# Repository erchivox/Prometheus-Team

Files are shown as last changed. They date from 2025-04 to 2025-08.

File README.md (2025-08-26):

# Prometheus Team

Somos un equipo venezolano que representa con orgullo a la **Universidad Politécnica Territorial José Félix Ribas (UPTJFR)**. Nuestro compromiso es la innovación y el aprendizaje continuo en el campo de la robótica autónoma.

---

##  Índice

* [Contenido del Repositorio](#contenido-del-repositorio)
* [Introducción al Proyecto](#introducción-al-proyecto)
* [Fotos de Equipo](#fotos-de-equipo)
* [Fotos del Vehículo](#fotos-del-vehiculo)
* [Diseño de Hardware](#diseño-de-hardware)
   * [Componentes de Detección](#componentes-de-detección)
   * [Componentes de Procesamiento de Información](#componentes-de-procesamiento-de-información)
   * [Componentes de Alimentación](#componentes-de-alimentación)
* [Desarrollo de la Aplicación para la Detección de Objetos](#Desarrollo-de-la-Aplicación-para-la-Detección-de-Objetos)
* [Cálculo de Torque y Velocidad](#cálculo-de-torque-y-velocidad)
* [Sistema de Alimentación](#sistema-de-alimentación)
   * [Cálculo del Consumo Energético Total](#cálculo-del-consumo-energético-total)
   * [Autonomía Estimada](#autonomía-estimada)
* [Sistema de Detección de Objetos](#sistema-de-detección-de-objetos)
* [Paso a Paso de la Construcción](#paso-a-paso-de-la-construcción)
   * [Etapa de Diseño y Ensamblaje del Vehículo](#etapa-de-diseño-y-ensamblaje-del-vehículo)
   * [Montaje del Vehículo](#montaje-del-vehículo)
   * [Diseño de Base 3D](#diseño-de-base-3d)
   * [Cambio de Base](#cambio-de-base)
   * [Problemas Encontrados](#problemas-encontrados)
* [Pruebas Realizadas](#pruebas-realizadas)
   * [Prueba del Sensor de Color](#prueba-del-sensor-de-color)
   * [Fabricación de Pista a Escala](#fabricacion-de-pista-a-escala)
   * [Desarrollo de la Lógica de Vueltas a la Pista](#desarrollo-de-la-logica-de-vueltas-a-la-pista)
   * [Desarrollo de la Lógica de Evasión de Objetos](#desarrollo-de-la-logica-de-evasion-de-objetos)
   * [Desarrollo de Códigos Combinados](#desarrollo-de-códigos-combinados)
   * [Video Resumen de las Pruebas](#video-resumen-de-las-pruebas-de-vuelta-a-la-pista-y-esquive-de-objetos)
   * [Prueba de Vueltas a la Pista](#prueba-de-vueltas-a-la-pista)
   * [Prueba de Evasión de Obstáculos](#prueba-de-evacion-de-obstaculos)
---

##  Contenido del Repositorio

Este repositorio contiene los siguientes directorios para organizar nuestro proyecto:

* `t-photos`: Incluye 2 fotos del equipo (una oficial y una divertida con todos los miembros).
* `v-photos`: Contiene 6 fotos del vehículo (desde todos los ángulos, superior e inferior).
* `video`: Archivo `video.md` con el enlace a un video de demostración de conducción.
* `schemes`: Diagramas esquemáticos (JPEG, PNG o PDF) de los componentes electromecánicos, ilustrando la conexión de elementos electrónicos y motores.
* `src`: Código del software de control para todos los componentes programados para la competición.
* `models`: Archivos para modelos usados por impresoras 3D, cortadoras láser y máquinas CNC para producir elementos del vehículo.
* `other`: Archivos adicionales para entender cómo preparar el vehículo para la competición (documentación de conexión SBC/SBM, carga de archivos, especificaciones de hardware, etc.).

---

##  Introducción al Proyecto

Para esta competición, hemos desarrollado un diseño de vehículo **cómodo, fácil de modificar y sencillo**, donde todos los elementos interactúan a la perfección. Nos enorgullece presentar nuestro primer prototipo de vehículo autónomo con reconocimiento de objetos y colores.

El diseño y la construcción de nuestro vehículo son íntegramente propios. Su **estructura de dos niveles** permite que todos los componentes encajen armoniosamente. Incorpora **vigas de soporte extraíbles** para facilitar el desmontaje, un **sistema de transmisión** tipo LEGO que transfiere la potencia del motor a las ruedas traseras, y un **sistema de dirección** también con piezas LEGO, controlado por un servomotor para mayor precisión en los giros.

Este proyecto ha sido el resultado del esfuerzo y la dedicación de todo nuestro equipo. Cada cable, cada sensor, y cada línea de código es un testimonio de nuestro **esfuerzo técnico y financiero**. No solo construimos un vehículo; demostramos que con pasión y ganas de aprender, se pueden superar los límites.

---
##  Fotos de equipo
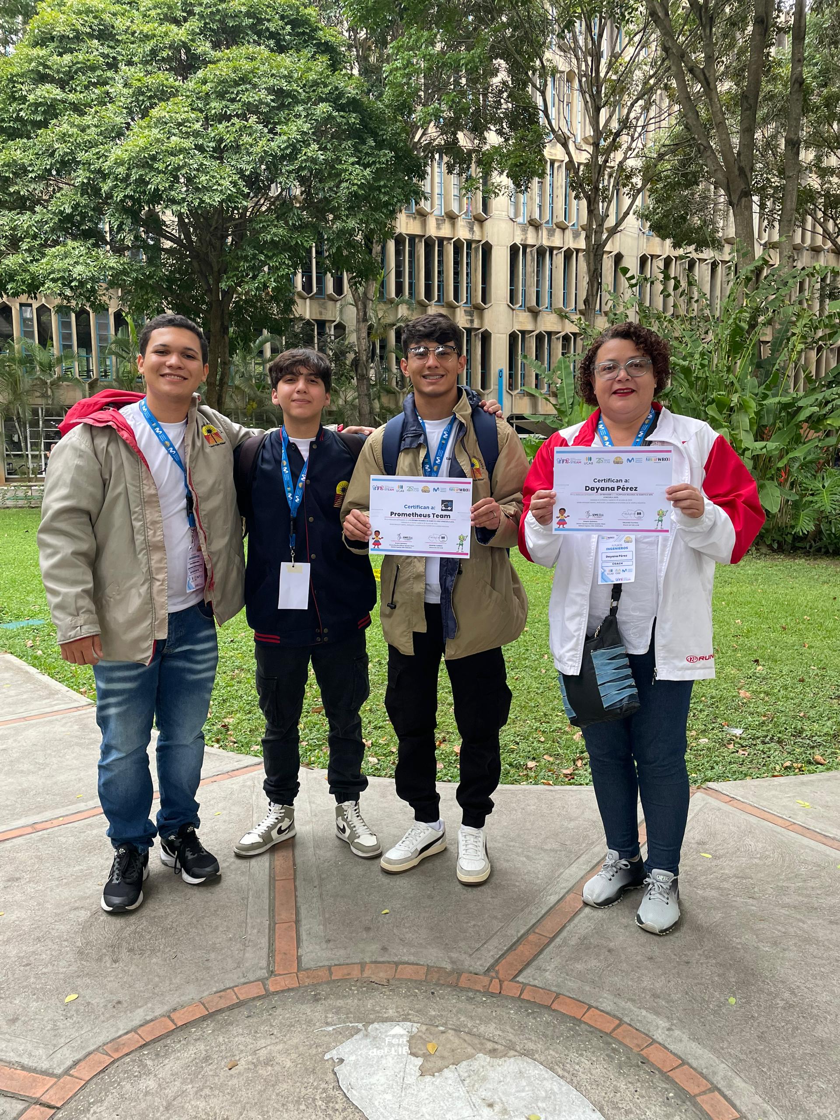
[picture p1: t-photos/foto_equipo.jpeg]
Foto Oficial
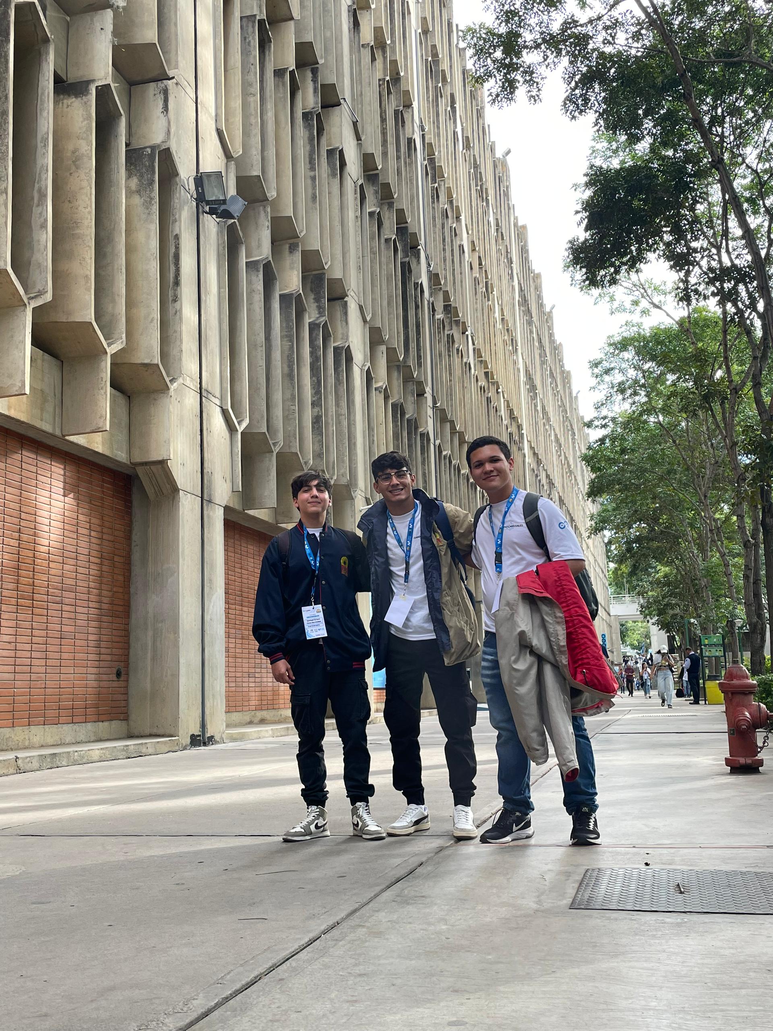
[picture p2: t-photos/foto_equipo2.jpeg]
Foto Equipo
|   |  | 
| :----: | :--- |

---
##  Fotos del vehiculo 
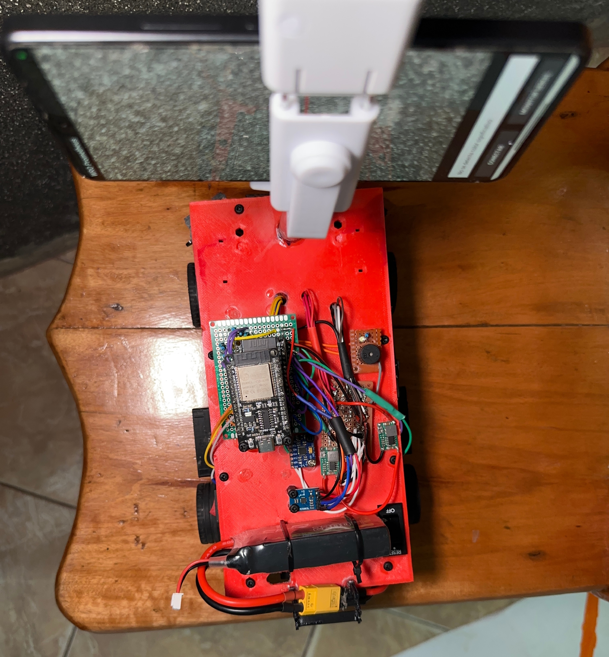
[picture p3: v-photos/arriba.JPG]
Arriba del vehiculo
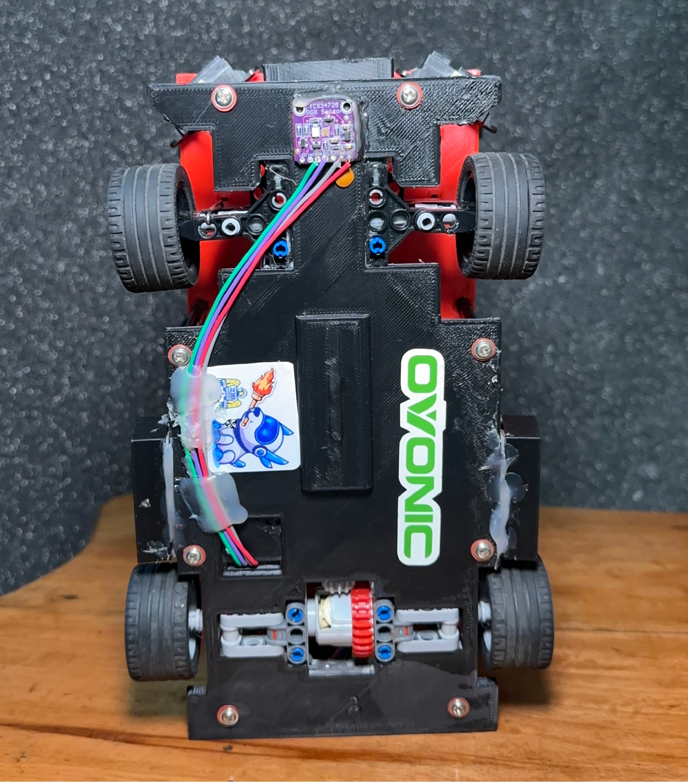
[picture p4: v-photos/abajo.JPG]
Debajo de vehiculo
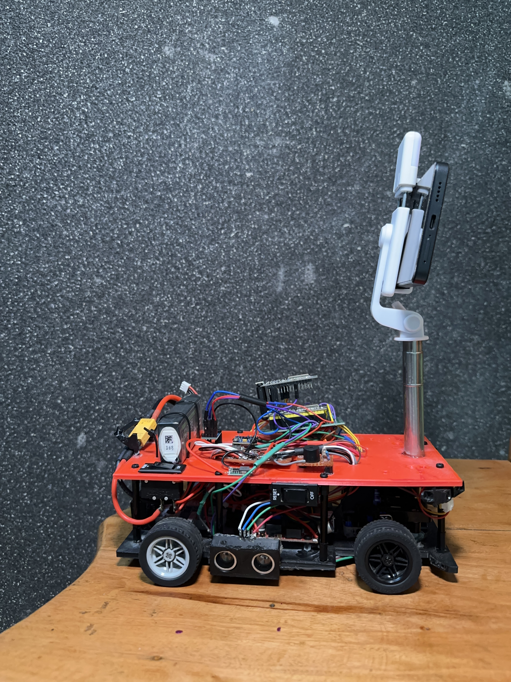
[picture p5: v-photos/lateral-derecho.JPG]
Lateral derecho
|   |    |   |
| :----: | :--- | :--- |
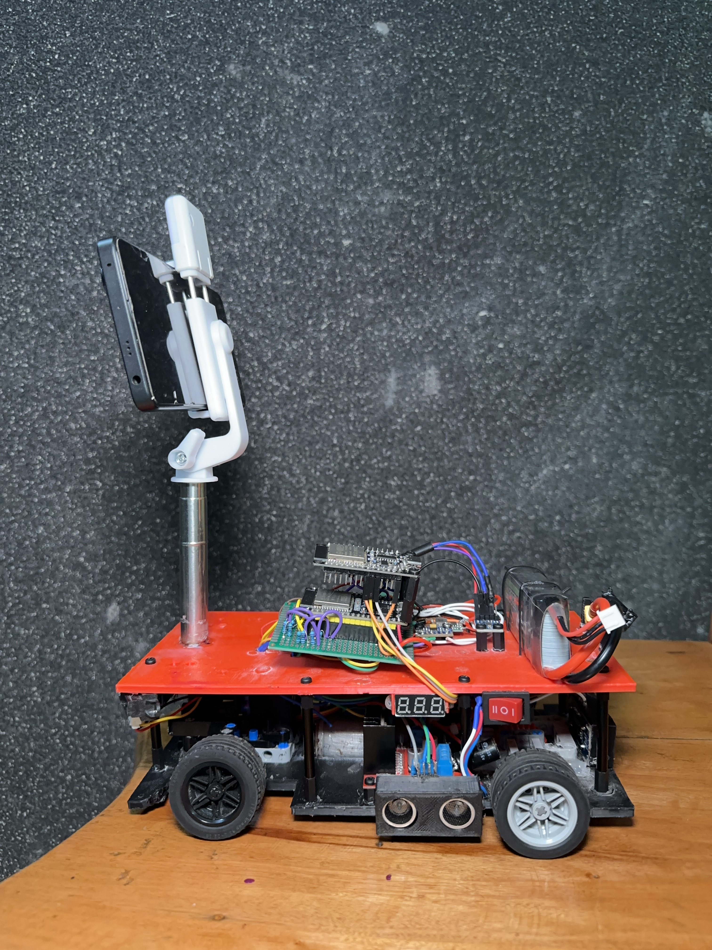
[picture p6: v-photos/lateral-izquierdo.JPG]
lateral izquierdo
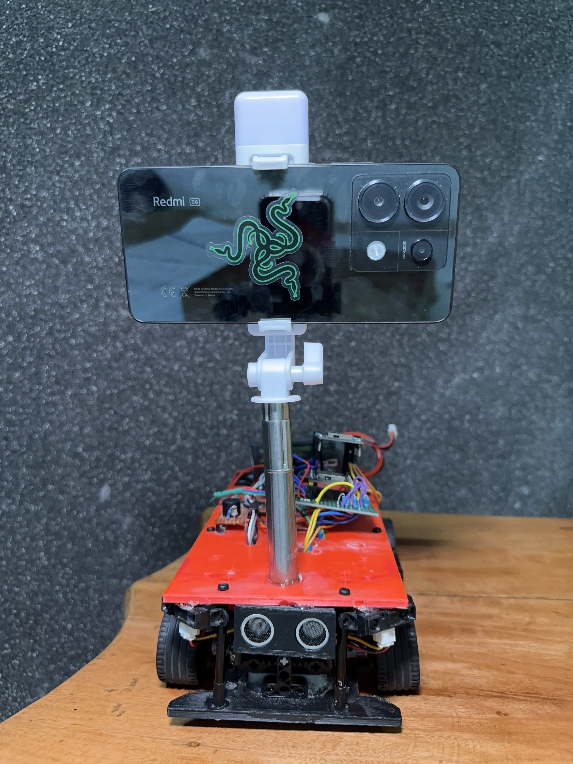
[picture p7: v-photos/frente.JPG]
frente
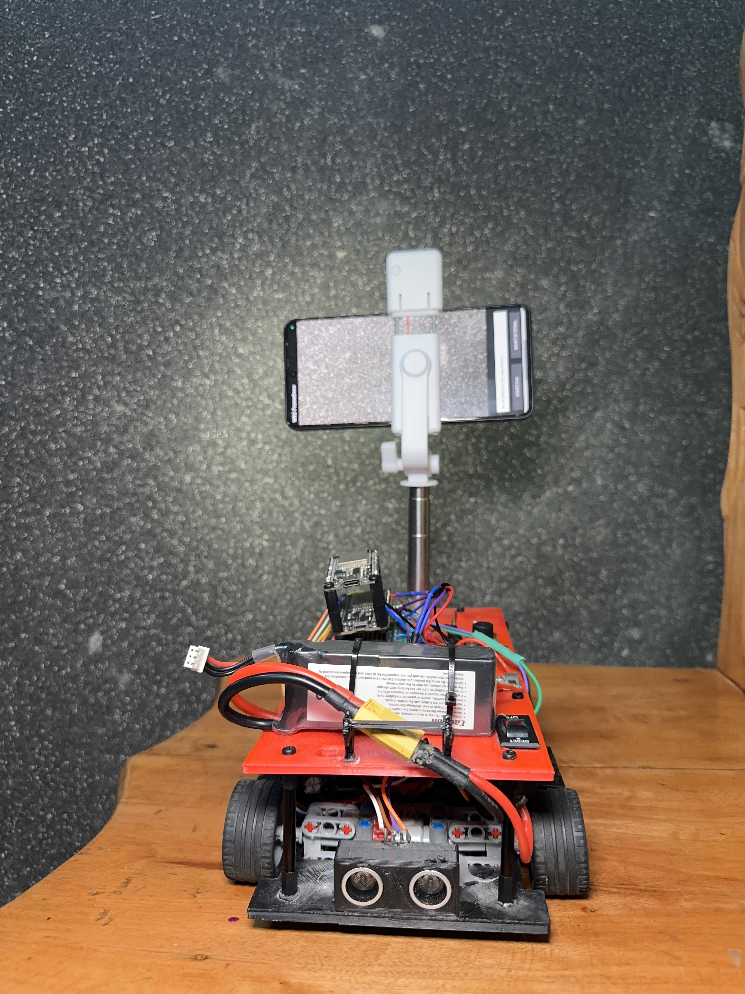
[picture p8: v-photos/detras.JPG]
detras
|   |    |   |

---

##  Diseño de Hardware

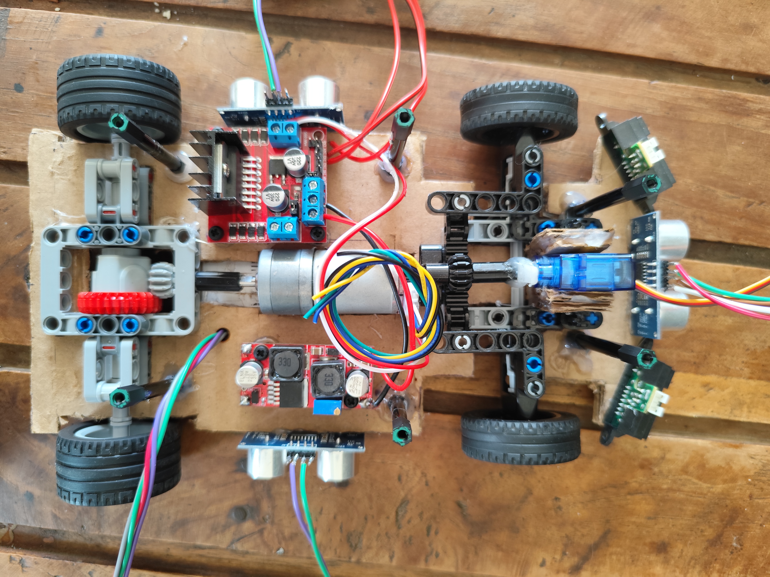
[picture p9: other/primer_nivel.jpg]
Control Principal


| Imagen | Nombre de Componente | Descripción |
| :----: | :--- | :--- |
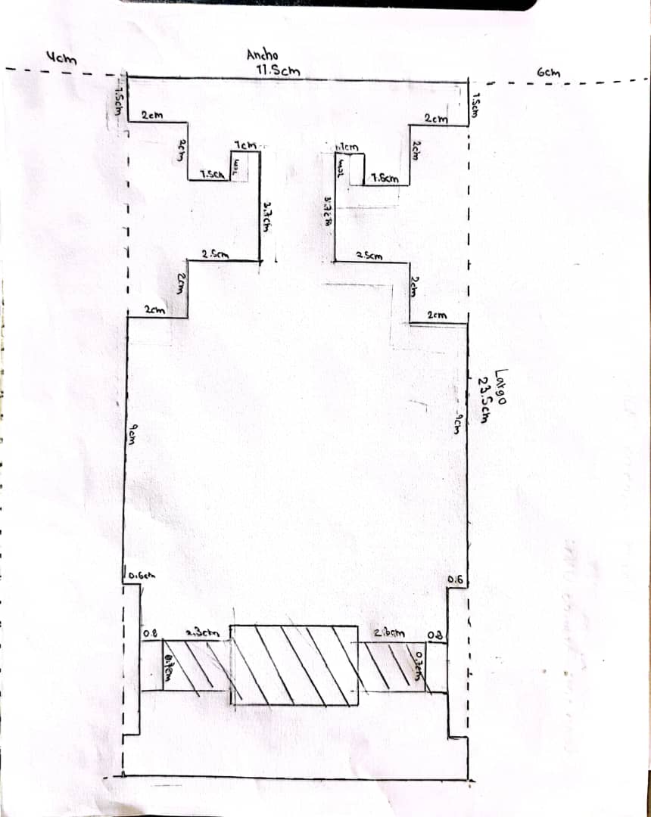
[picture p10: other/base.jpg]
Base del Primer Piso
|  | **Base del Vehículo** | Con medidas de 11.5 cm x 2.5 cm, imita un coche de Fórmula 1, optimizando la distribución de espacio y la movilidad. La parte frontal permite alojar tres sensores (1 ultrasónico central y 2 infrarrojos diagonales). Aunque el cartón inicial presentó debilidades en la dirección, el uso de acrílico o un material más rígido es la solución ideal. |
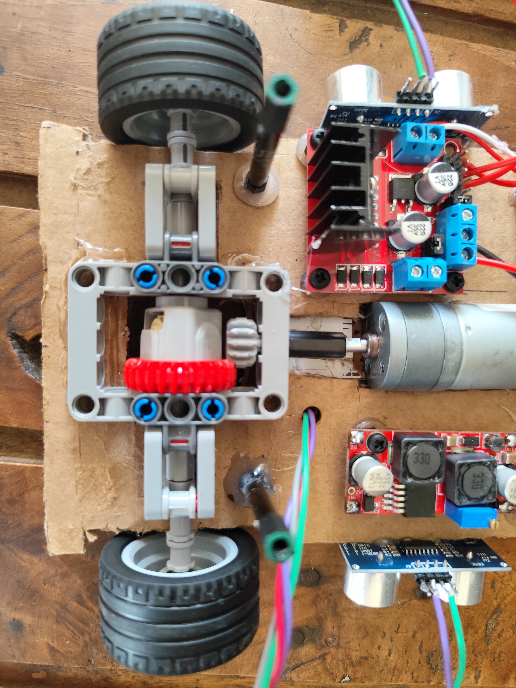
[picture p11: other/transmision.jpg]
Transmisión
|  | **Sistema de Transmisión de Legos** | Distribuye la potencia del motor entre ambas ruedas traseras, permitiendo el giro continuo del motor incluso si una rueda se bloquea y evitando daños. Elegido por su facilidad de uso y tamaño adecuado, permite también la reversa. |
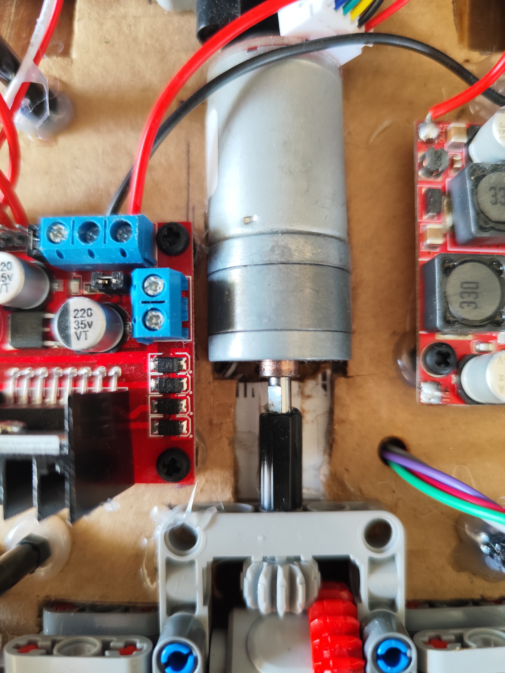
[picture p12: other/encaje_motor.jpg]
Motor
|  | **25GA370 Motor DC con Encoder** | Motor común en estos vehículos por su potencia y velocidad. El codificador integrado mide velocidad y dirección (aún no utilizado). **Especificaciones**: Potencia nominal: 4 W, Tensión nominal: 6V, Velocidad nominal: 220 RPM, Peso: 400g, Caja reductora: 21.3:1, Torque nominal: 0.35 kg·cm. |
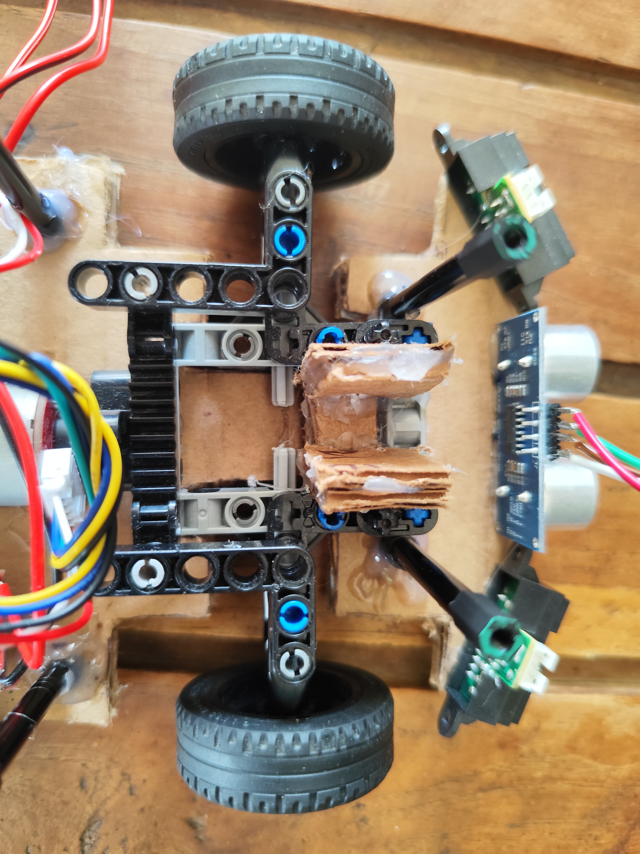
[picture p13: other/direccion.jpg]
Dirección
|  | **Sistema de Dirección** | Construido con piezas LEGO, su tamaño es ideal y permite adaptar un servomotor de 180 grados para controlar el movimiento. El servomotor se centra a 90 grados, gira a la izquierda a 180 grados y a la derecha a 0 grados. |
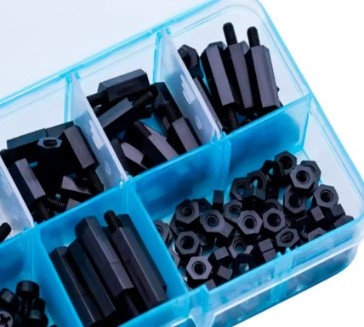
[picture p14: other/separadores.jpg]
Separadores
|  | **Separadores de Acrílico** | Facilitan un montaje cómodo y modular. Girar los pilares permite desatornillar y desmontar el vehículo rápidamente. |

### Componentes de Detección

| Imagen | Nombre de Componente | Descripción |
| :----: | :--- | :--- |
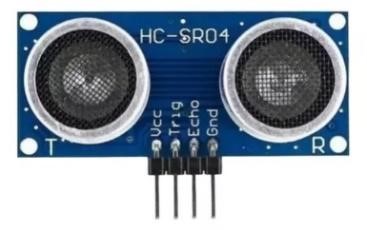
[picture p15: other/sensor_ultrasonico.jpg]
Sensor Ultrasónico
|  | **Sensor Ultrasónico HC-SR04** | Mide la distancia a obstáculos mediante ondas ultrasónicas. Lo utilizamos en la parte frontral, lateral izquierda, lateral derecha y en la parte trasera del vehiculo para detectar proximidad. |
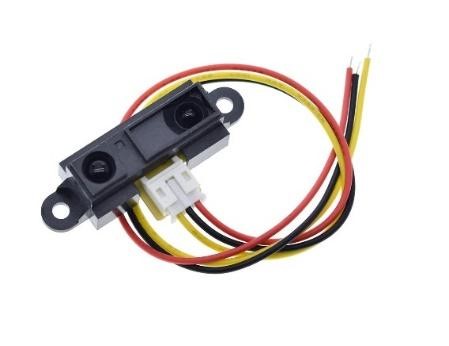
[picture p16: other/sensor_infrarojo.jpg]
Sensor Infrarrojo
|  | **Sharp GP2Y0A21YK0F Sensor Infrarrojo** | Garantiza una detección de objetos rápida y precisa. Se ubican en las diagonales delanteras del vehículo. |
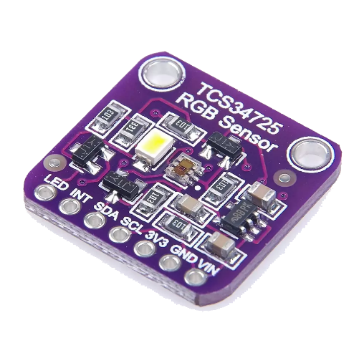
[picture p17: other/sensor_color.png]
Sensor Color
|  | **TCS34725 Sensor de Colores** | Permite una detección precisa del color a corta distancia, ubicado en la parte inferior para identificar los colores de las franjas de la pista. Alta sensibilidad y amplio rango dinámico (3.800.000:1), funcionando incluso tras cristales oscuros. |
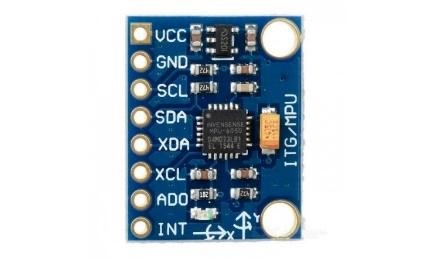
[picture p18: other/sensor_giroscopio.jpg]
Giroscopio
|  | **MPU6050 Sensor Giroscopio y Acelerómetro** | Unidad de medición inercial (IMU) de 6 grados de libertad (DoF) que combina un acelerómetro y un giroscopio de 3 ejes. Ampliamente utilizado en navegación, radiogoniometría y estabilización. |
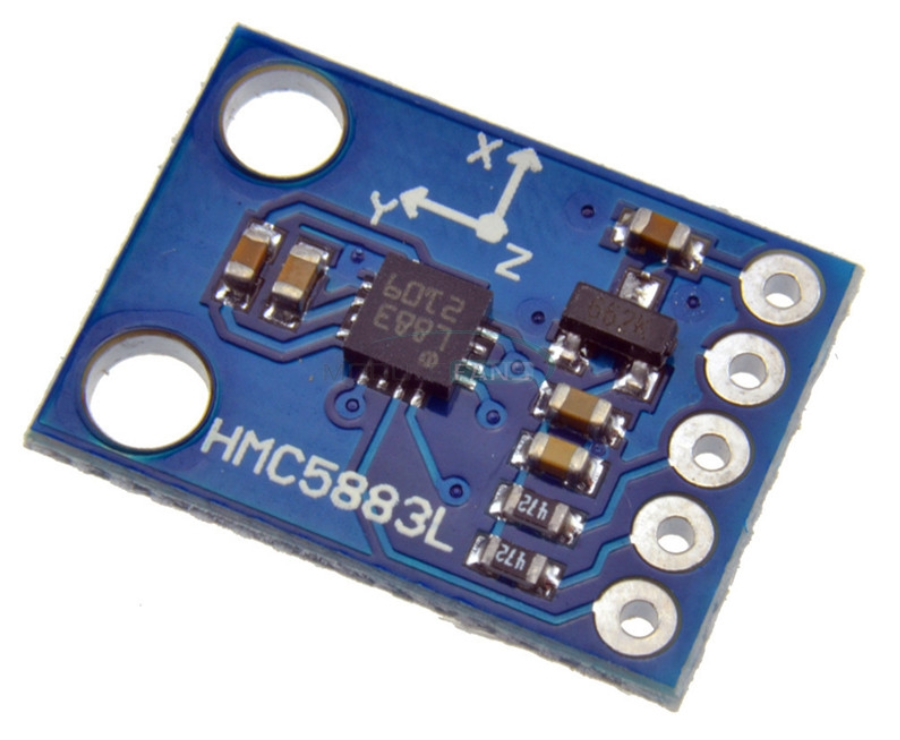
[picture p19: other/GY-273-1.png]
Magnetometro
|  | **Magnetómetro GY-273 HMC5883L** | Funciona como una brújula digital, midiendo la intensidad y la dirección del campo magnético de la Tierra en sus tres ejes (X, Y, Z). Al detectar este campo, puede determinar su orientación con respecto al norte magnético. |
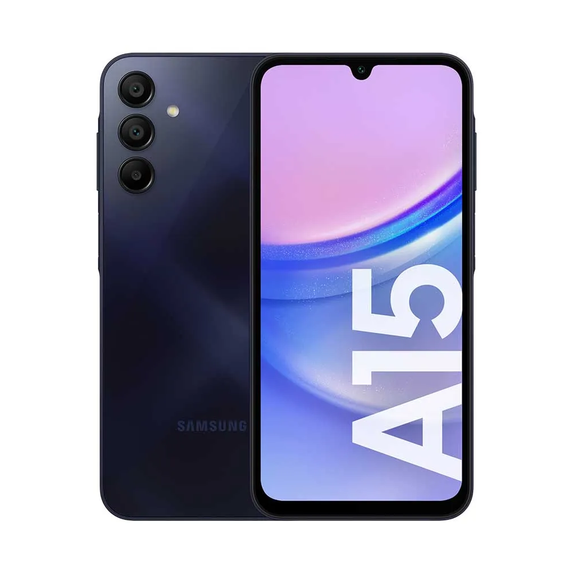
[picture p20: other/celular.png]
Cámara Celular
|  | **Cámara del Teléfono Celular** | Utilizando una app desarrollada en android studio usando las librerias de OpenCV, el celular en general se usa como procesador de imagenes y la cámara del celular se usa como sensor para identificar el color y los objetos. |

### Componentes de Procesamiento de Información

| Imagen | Nombre de Componente | Descripción |
| :----: | :--- | :--- |
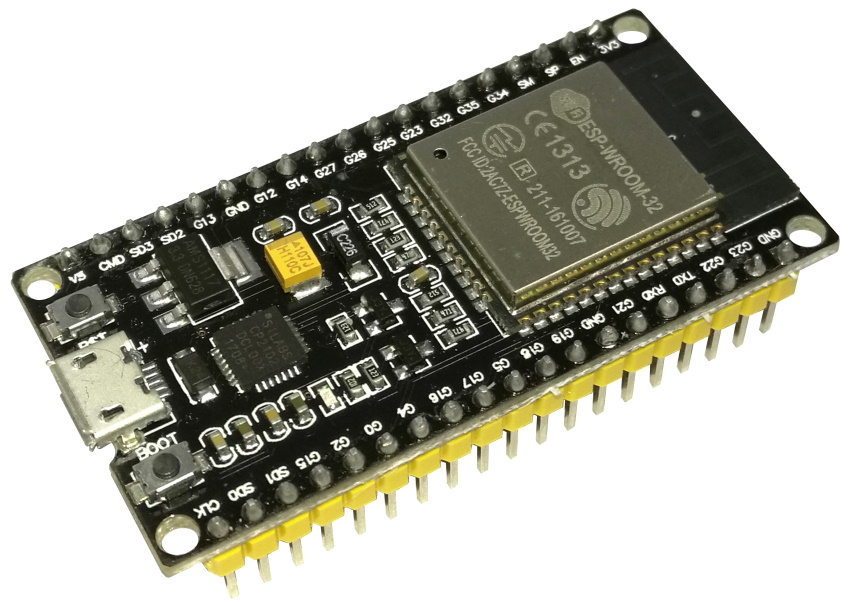
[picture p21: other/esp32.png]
ESP32
|  | **Microcontrolador ESP32** | Actúa como el cerebro del vehículo, conectando y controlando todos los sensores y motores. |

### Componentes de Alimentación

| Imagen | Nombre de Componente | Descripción |
| :----: | :--- | :--- |
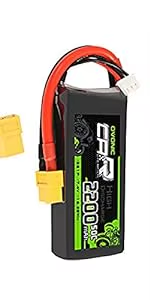
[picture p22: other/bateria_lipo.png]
Batería
|  | **Batería LiPo 2200mAh 7.4V** | Fuente de alimentación recargable que alimenta todo el sistema, proporcionando movilidad y autonomía. Seleccionada por su capacidad para suministrar suficiente energía a los motores y componentes internos. |
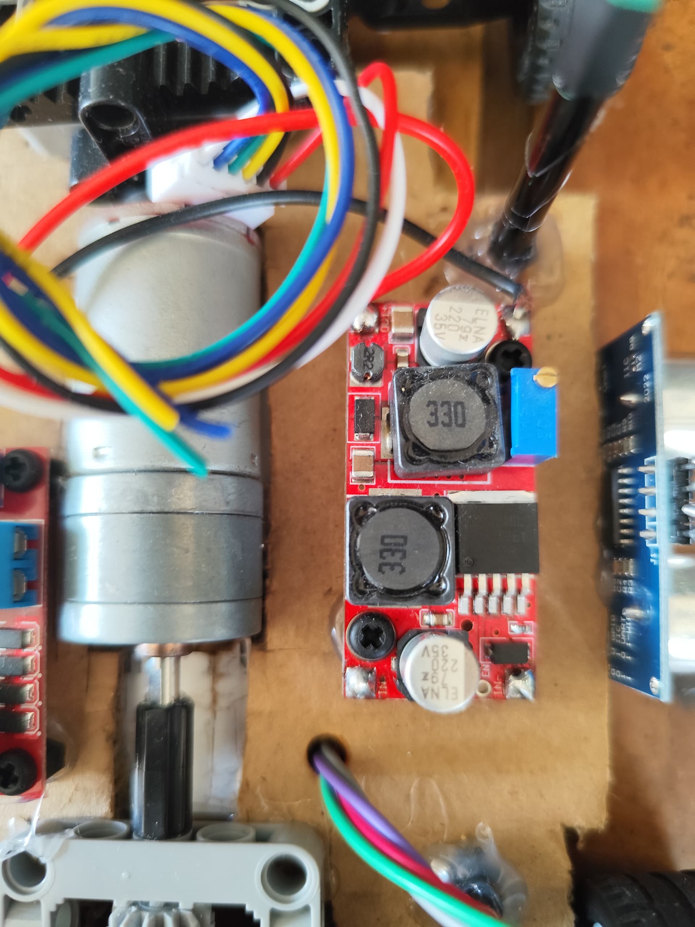
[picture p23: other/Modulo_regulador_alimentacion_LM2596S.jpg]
Regulador
|  | **LM2596 Regulador de Voltaje** | Reduce el voltaje de manera eficiente. Voltaje de entrada: 4.5 V a 40 V CC. Voltaje de salida: 1.23 V a 37 V CC. Corriente de salida: Máx. 3 A, se recomiendan 2.5 A. |

---

# Desarrollo de la Aplicación para la Detección de Objetos

Para la detección de obstáculos, hemos desarrollado una aplicación móvil usando **Android Studio** e implementando la biblioteca **OpenCV**, la app es el cerebro de nuestro vehículo autónomo en cuanto a resolución de obstáculos se refiere. Permite que nuestro vehiculo identifique y reaccione de forma inteligente a los obstáculos en su entorno. El sistema procesa imágenes en tiempo real capturadas por la cámara del teléfono y, mediante una comunicación serial confiable, envía comandos específicos a una placa **Arduino/ESP32** para controlar el comportamiento del vehiculo en el campo de competición.

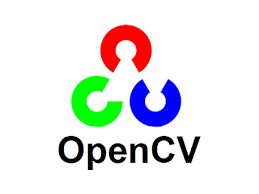
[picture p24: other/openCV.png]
Logo de OpenCV
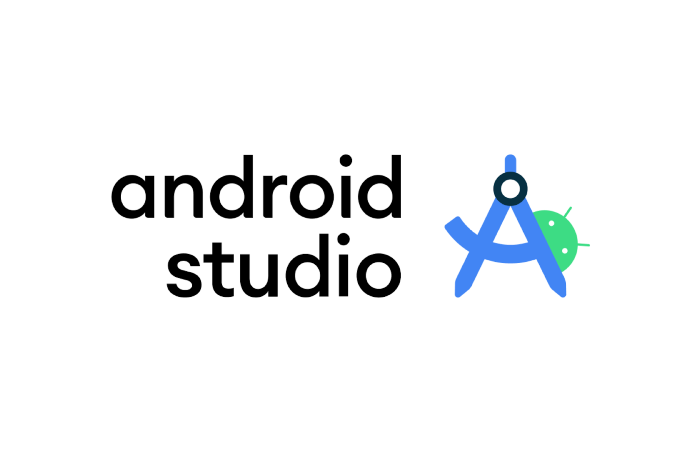
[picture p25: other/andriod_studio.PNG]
Logo de Android Studio
|  |  |
| :---: | :---: |

---
A continuación, detallaremos algunas de las versiones más importantes de nuestra aplicación, mostrando la evolución del sistema de detección a lo largo del desarrollo y cómo cada etapa nos ayudó a superar los desafíos del proyecto.

## Versión 1: Detección Básica de Colores

Esta es la primera versión del sistema, enfocada en la detección simple de colores. Su objetivo principal era identificar objetos de color **rojo** y **verde** para enviar un comando básico (`R` para rojo, `G` para verde) a través de una conexión USB a la placa Arduino.

El mayor reto en esta etapa fue lograr la comunicación efectiva entre un dispositivo móvil Android y un microcontrolador como el Arduino. Después de numerosos intentos y ajustes, se consiguió establecer una conexión estable y que el Arduino recibiera comandos, al menos de forma básica. Además, fue un desafío significativo lograr aprovechar al máximo la librería **OpenCV** en un entorno móvil, dadas las complejidades de su instalación y configuración en dispositivos Android, pero este obstáculo también fue superado con éxito.

**Imágenes de la Versión 1:**

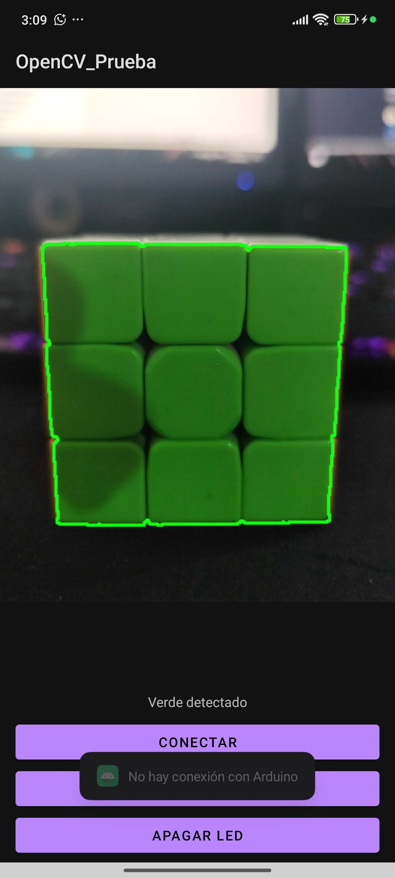
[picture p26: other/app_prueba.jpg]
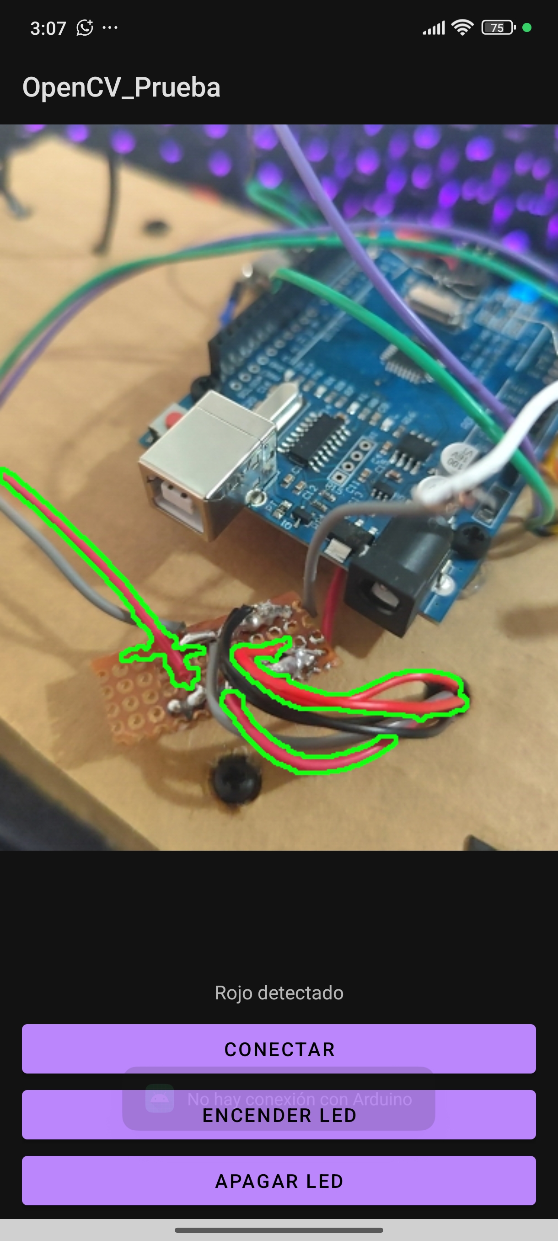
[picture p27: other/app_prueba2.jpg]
|  |  |
| :---: | :---: |

---

---

---

## Versión 2: Mejora en Detección y Comunicación

Se introdujeron mejoras significativas para hacer el sistema más robusto y preciso. Uno de los principales retos fue **optimizar la aplicación** para que los comandos se enviaran y fueran recibidos por el Arduino lo más rápido posible, al mismo tiempo que se lograba reconocer con precisión la **distancia** y **orientación** del objeto.

Con respecto a la orientación, una complicación particular surgió debido a la **posición horizontal de la cámara** en el teléfono. Al dividir la pantalla en tres sectores para determinar la ubicación del objeto, la perspectiva de la cámara causaba distorsiones, haciendo que un objeto pareciera estar más hacia un lado del vehículo de lo que realmente estaba.

### Cálculo de Distancia por Área

Para estimar la distancia al objeto, se implementó un método basado en la relación inversa entre la distancia y el área aparente del objeto en la imagen. El principio es simple: **cuanto más lejos está un objeto, más pequeño se ve**. Este enfoque requiere una calibración inicial para funcionar.

La fórmula utilizada es la siguiente:

$$ \text{Distancia} = \text{DistanciaConocida} \times \sqrt{\frac{\text{AreaConocida}}{\text{AreaMedida}}} $$

Donde:
* **DistanciaConocida**: Es una distancia fija y conocida a la que se calibra el sistema (por ejemplo, 30 cm).
* **AreaConocida**: Es el área en píxeles que ocupa el objeto en la imagen cuando se encuentra a la `DistanciaConocida`. Este valor se guarda una vez durante la calibración.
* **AreaMedida**: Es el área actual en píxeles que el objeto ocupa en la imagen durante la detección en tiempo real.

Este método permite que, tras una única calibración, el sistema pueda estimar la distancia de forma continua simplemente midiendo el tamaño del objeto detectado.

A pesar de los desafíos, se implementaron las siguientes mejoras:

* **Filtrado de Formas:** La aplicación ahora filtra las imágenes para reconocer específicamente **formas rectangulares**, lo que reduce los falsos positivos y mejora la precisión.
* **Comunicación Detallada:** Se mejoró la comunicación con Arduino para transmitir información más completa. Ahora se envían la **distancia** y la **orientación** del objeto, además de su color.
* **Mejoras en la UI:** Se optimizó el comportamiento general de la aplicación y se realizaron cambios sutiles en la interfaz de usuario para una mejor experiencia.

**Imágenes de la Versión 2:**

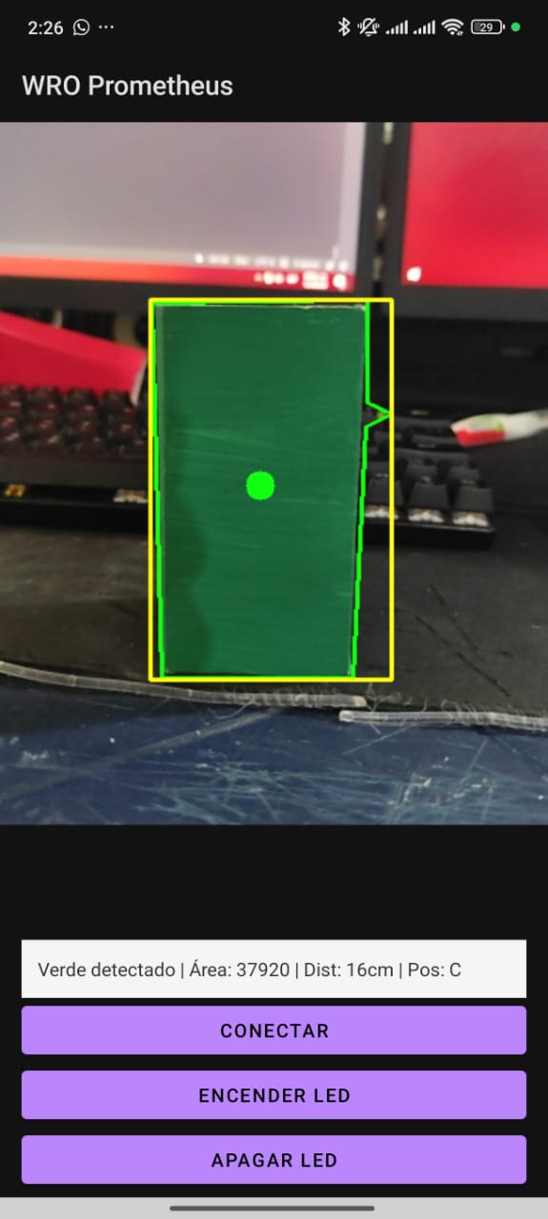
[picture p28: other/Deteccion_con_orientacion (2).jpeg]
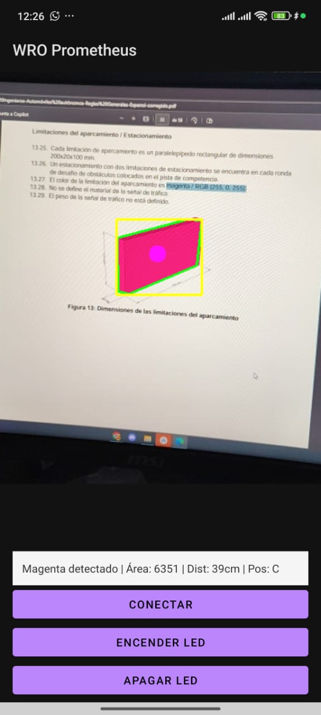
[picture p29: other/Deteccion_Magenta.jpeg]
|  |  |
| :---: | :---: |

---

## Versión 3: Sistema de Detección Avanzado y Profesional

Esta versión representa una **reestructuración completa** y un salto cualitativo en el sistema, adaptándose a las nuevas necesidades y a un cambio en la plataforma del vehículo. Tras evaluar los resultados obtenidos en los regionales del país, se hizo evidente la necesidad de un sistema más avanzado y robusto capaz de mejorar significativamente el **esquive de obstáculos**.

Para ello, se realizó un cambio en el vehículo para usar un ESP32 como microcontrolador principal, lo que requirió que la aplicación también se adaptara a esta nueva plataforma. La estrategia clave fue desarrollar un sistema capaz de reconocer dos objetos a la vez y establecer rutas de forma anticipada, en lugar de esquivar los obstáculos uno a uno en tiempo real. Esto llevó la automatización de nuestro vehículo a otro nivel.

Sin embargo, la implementación de la detección dual presentó varios desafíos. El más evidente fue que requirió rehacer gran parte del código de envío de comandos. Para resolverlo, decidimos crear un archivo independiente, el CommandManager, que se encarga exclusivamente de la lógica de comandos y de gestionar la información de cada combinación de obstáculos o "caso".

Además, surgió la necesidad de elevar el teléfono para que la cámara pudiera observar ambos objetos cuando uno estuviera detrás del otro. Esto nos obligó a realizar una modificación en la base del vehículo, un cambio que se detalla más a fondo en la sección correspondiente de nuestro repositorio. Finalmente, una vez resueltos estos retos, se llevaron a cabo una gran cantidad de pruebas para asegurar que el sistema fuera robusto y pudiera enfrentar de manera fiable las distintas combinaciones de obstáculos en la competición.
Se lograron importantes avances:

* **Solución al Problema de Orientación:** Se corrigió el problema anterior con la división de la pantalla y la orientación. En esta versión, no usamos una división en tres sectores; simplemente dividimos la pantalla en **izquierda y derecha** para identificar la posición lateral de los objetos.
* **Cálculo de Distancia Avanzado:** El cálculo de distancia se encarga de identificar la posición longitudinal de los objetos (adelante, medio o atrás). Mediante algunos "trucos" y algoritmos optimizados, logramos filtrar y reconocer de manera efectiva **cada caso de colisión o esquive**.
* **Interfaz Profesional:** La interfaz de usuario fue completamente **rediseñada** para ser más intuitiva, profesional y pulida, ofreciendo una experiencia de usuario superior.
* **Monitor Serial Integrado:** La incorporación de un **monitor serial** para recibir información directamente del microcontrolador ha sido fundamental para el **debug** y las pruebas en tiempo real, agilizando el desarrollo.
* **Diseño Único:** La nueva interfaz no solo es 100% más práctica, sino que también cuenta con un diseño único que representa la identidad de nuestro equipo: **Prometheus Team**.

**Imágenes de la Versión 3:**
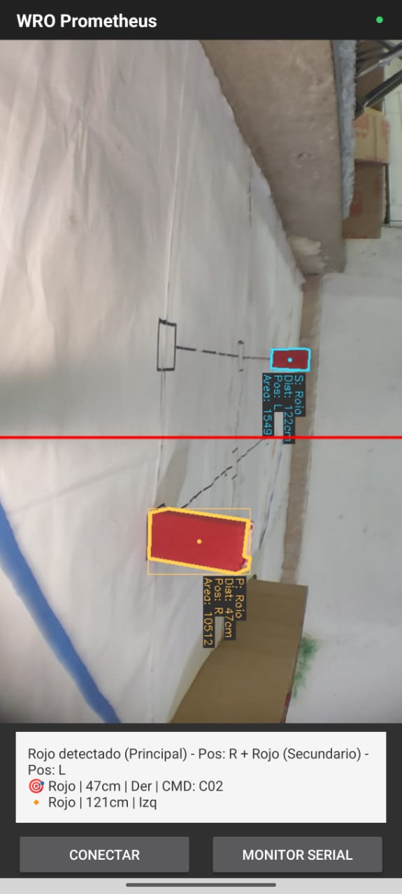
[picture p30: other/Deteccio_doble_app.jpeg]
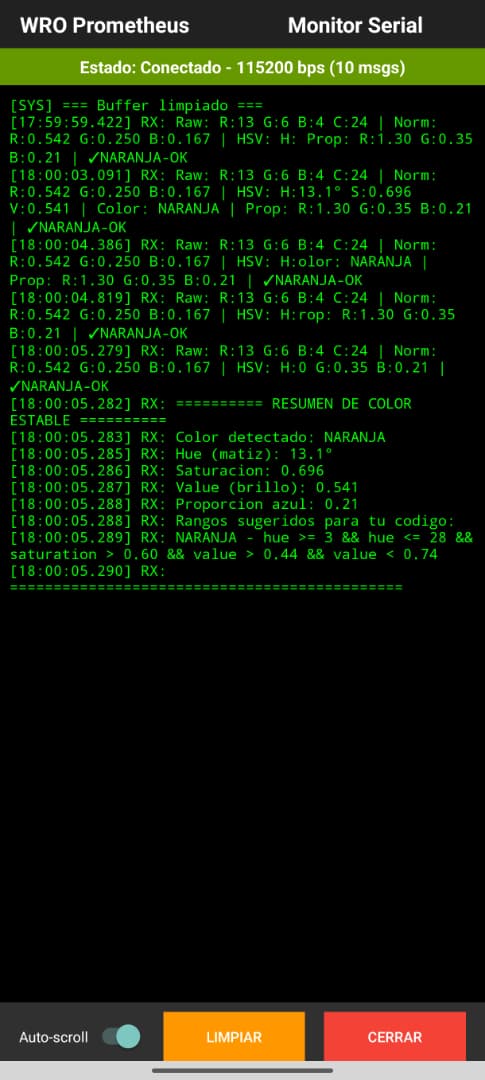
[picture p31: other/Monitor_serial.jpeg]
|  |  |
| :---: | :---: |

---

##  Flujo de Proceso de la Aplicación 

El sistema opera como un ciclo continuo de detección y envío de comandos, con tres componentes principales: la interfaz de usuario, el análisis de imágenes y la comunicación serial.

### Flujo Detallado

* **Inicio y Conexión Automática (`MainActivity`):** Al iniciar, la aplicación solicita los permisos de la cámara e inicializa las librerías de OpenCV. La aplicación no requiere que el usuario conecte manualmente el dispositivo, ya que es capaz de detectar automáticamente el microcontrolador (Arduino/ESP32) y establecer la comunicación serial de forma autónoma.
* **Captura y Análisis de la Imagen (`ColorAnalyzer`):** Un hilo de alta prioridad se encarga de capturar continuamente imágenes de la cámara. Cada fotograma se envía al `ColorAnalyzer` para su procesamiento.
* **Preprocesamiento:** El `ColorAnalyzer` convierte el fotograma y aplica técnicas avanzadas como la ecualización de histograma para normalizar la iluminación.
* **Detección de Colores y Formas:** La aplicación crea "máscaras" para aislar los colores de los obstáculos (rojo, verde y magenta) y busca contornos en esas máscaras, aplicando filtros geométricos para detectar pilares rectangulares.
* **Cálculo de Distancia:** Se calcula el área de cada objeto detectado en píxeles para estimar su distancia en centímetros.
* **Generación de Comandos (`CommandManager`):** La información del objeto detectado (color, distancia y posición en la imagen) se envía al `CommandManager`. Este módulo compara los datos del objeto con "casos" predefinidos para la detección de uno o dos objetos y determina el código de comando adecuado.
* **Envío del Comando (`MainActivity`):** El comando generado se añade a una cola de procesamiento. Un hilo dedicado a la comunicación USB lee la cola y envía el comando al microcontrolador a través del puerto serial, con una pausa mínima para evitar la saturación.
* **Monitoreo (`SerialMonitorActivity`):** Una actividad separada permite al usuario monitorear en tiempo real los datos que se envían y reciben, lo cual es útil para la depuración del sistema.

### Puntos Clave

* **Conexión Automática:** La aplicación se conecta automáticamente al microcontrolador al detectarlo, lo que agiliza el proceso de inicio.
* **Visión por Computadora Avanzada:** El uso de OpenCV con ecualización de histograma y filtros geométricos asegura una detección precisa de los pilares.
* **Doble Detección de Objetos:** La capacidad de diferenciar entre un objeto primario y uno secundario es fundamental para la navegación en el campo de la WRO.
* **Arquitectura de Hilos:** El uso de múltiples hilos separa las tareas de alto rendimiento (cámara, USB) del hilo principal, garantizando una operación fluida.
* **Sistema de Comandos Basado en Casos:** La lógica del `CommandManager` es clara y organizada, facilitando su mantenimiento y escalabilidad.
* **Comunicación USB Serial:** La conexión entre el teléfono y el robot se realiza de forma confiable a través de USB.

Diagrama de flujo, diseñado en Lucidchart, para una mejor visualización del funcionamiento de la aplicación WRO Prometheus.

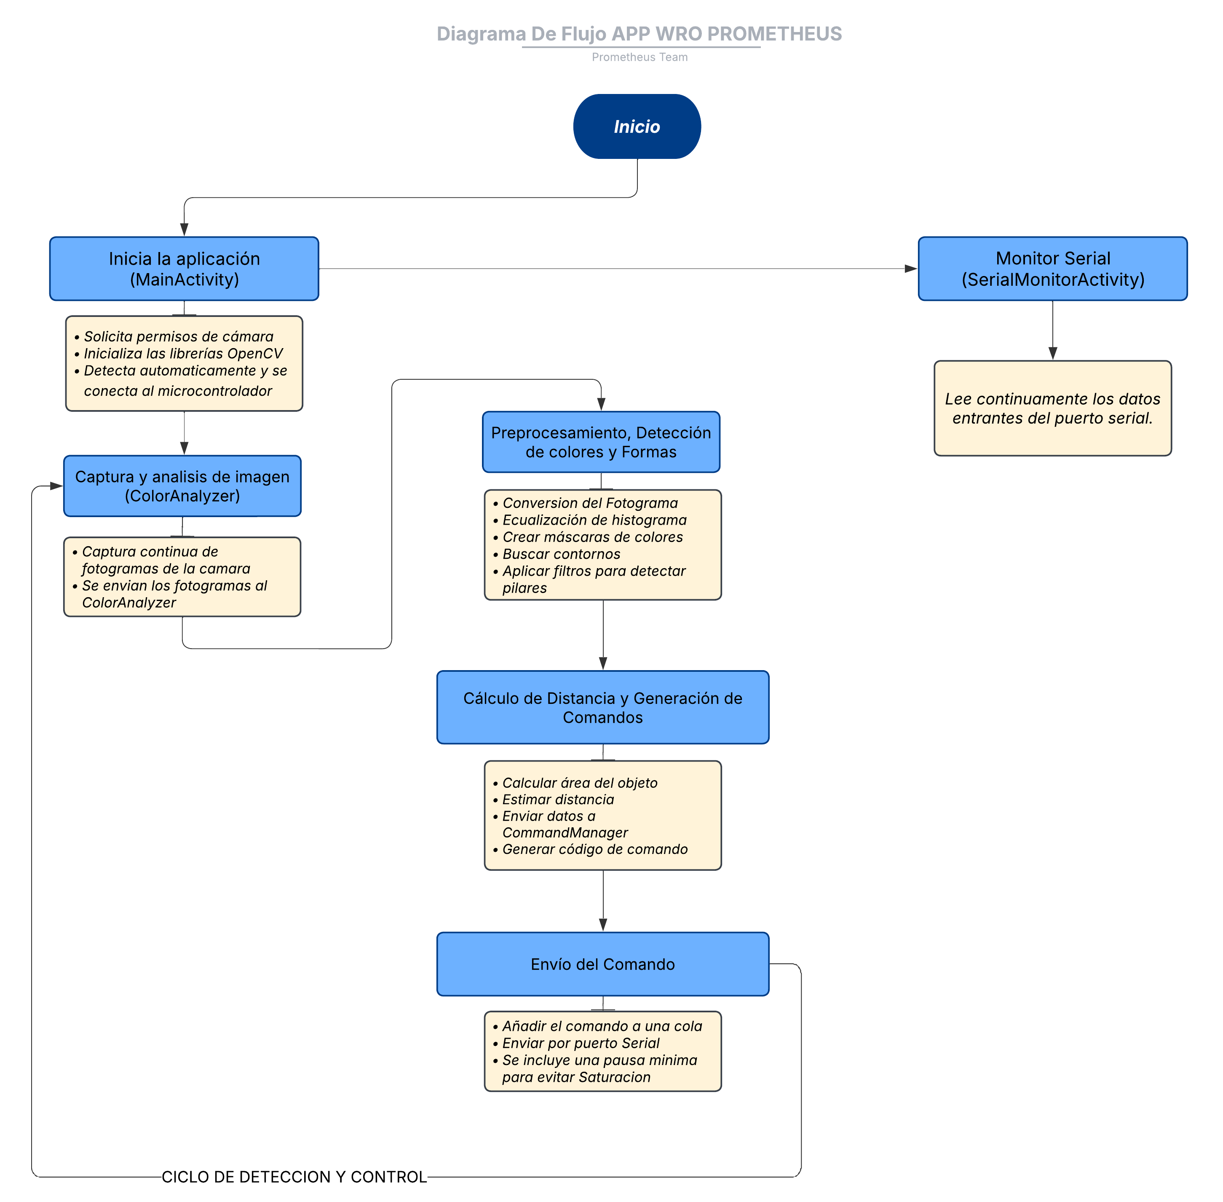
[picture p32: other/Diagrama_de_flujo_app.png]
Diagrama de Flujo de la Aplicación


----

### Video del Funcionamiento en Vivo de la Aplicación

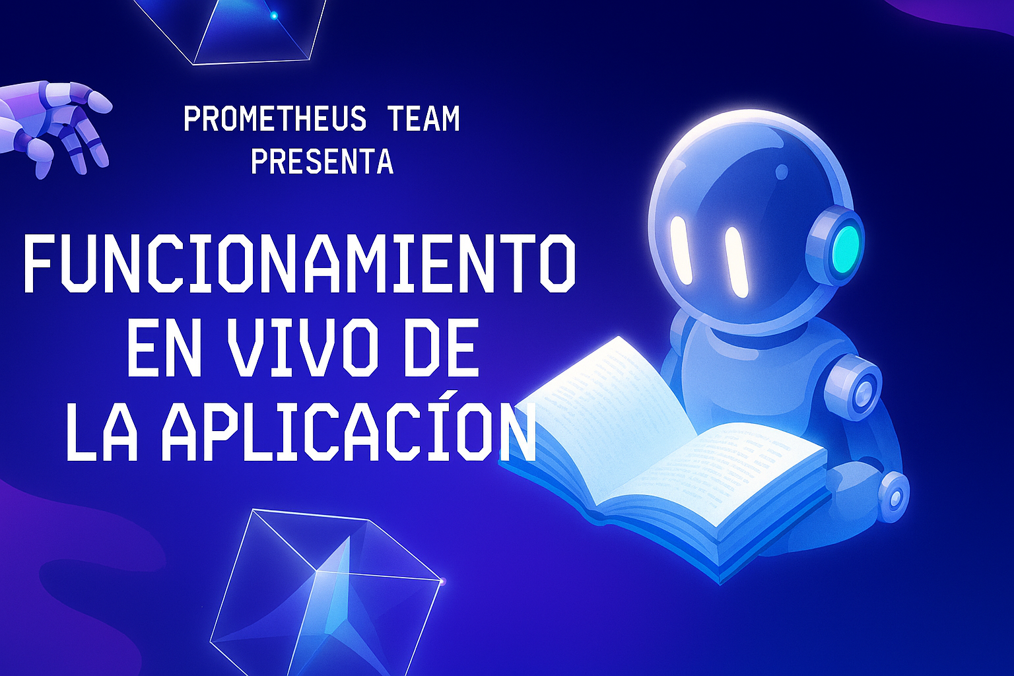
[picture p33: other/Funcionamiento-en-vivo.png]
Mira el video del funcionamiento en vivo de la aplicación (https://youtu.be/TpLVCiggEwY)


---

##  Cálculo de Torque y Velocidad

### Cálculo de Torque Necesario para Mover el Vehículo:

El torque necesario ($T_{\text{necesario}}$) se calcula mediante la fórmula:
$T_{\text{necesario}} = m \cdot g \cdot r$

Donde:
* $m$ = masa del vehículo (0.943 kg)
* $g$ = gravedad (9.81 $m/s^2$)
* $r$ = radio de las ruedas (0.04 m)

$T_{\text{necesario}} = 0.943 \cdot 9.81 \cdot 0.04 = 0.370 \text{ N} \cdot \text{m}$

### Cálculo de Torque a la Salida (después de la reducción) según el motor DC 25GA370:

$T_{\text{salida}} = T_{\text{motor}} \cdot \text{Reducción}$
$T_{\text{salida}} = 0.0343 \cdot 21.3 = 0.7306 \text{ N} \cdot \text{m}$

### Cálculo de la Velocidad Lineal del Vehículo:

Convertimos la velocidad del motor a radianes por segundo ($\omega$):
$\omega = \frac{220 \cdot 2\pi}{60} = 23.04 \text{ rad/s}$

Velocidad lineal del vehículo ($v$):
$v = \omega \cdot r = 23.04 \cdot 0.04 \approx 0.92 \text{ m/s}$

El motor empleado tiene una velocidad sin carga de 4690 RPM y un torque nominal de 0.35 kg·cm (0.0343 N·m). Mediante una caja reductora de 21.3:1, la velocidad se reduce a 220.2 RPM en el eje de salida, lo que resulta en una velocidad lineal del vehículo de aproximadamente 0.92 m/s.

Gracias a esta reducción, el torque en las ruedas alcanza 0.7306 N·m, lo cual supera el torque mínimo necesario para mover el vehículo de 943 gramos (0.370 N·m). Por lo tanto, el sistema cumple adecuadamente los requerimientos de tracción y movilidad para condiciones normales.

---

##  Sistema de Alimentación

###  Versión 1:

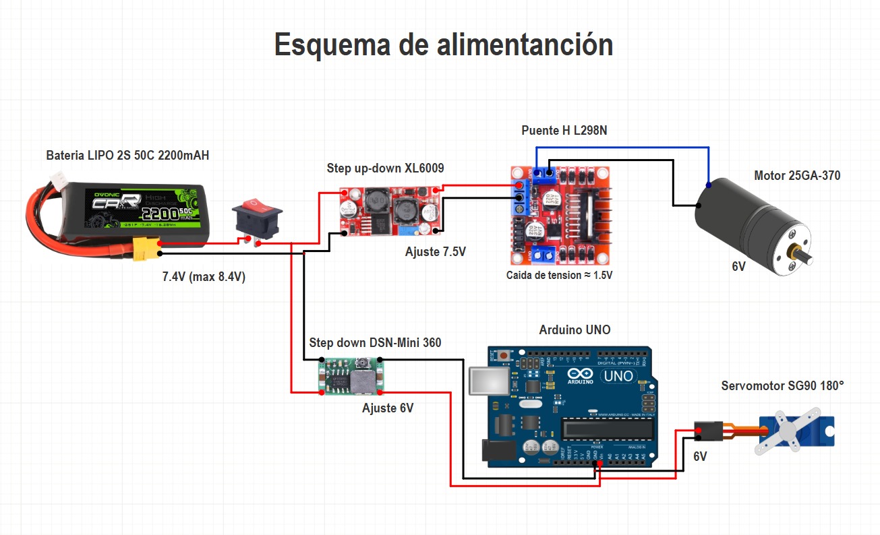
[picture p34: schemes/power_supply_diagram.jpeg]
Diagrama de Alimentación 1


Este diagrama representa la versión inicial del sistema de alimentación de nuestro proyecto, concebido con una configuración de componentes más simple. 

En esta iteración, el circuito se alimenta por completo a través de una **batería LiPo de 2200 mAh** (7.4V), cuya energía se distribuye a los distintos módulos después de pasar por un interruptor principal de encendido. Un **regulador de voltaje XL6009** eleva el voltaje para alimentar el puente H **L298N**, asegurando que nuestro motor DC reciba la tensión de funcionamiento adecuada. 

De forma paralela, un **módulo DSN-Mini 360** se encarga de reducir el voltaje de la batería para alimentar directamente el pin Vin de la placa **Arduino**, que a su vez controla el servomotor de dirección. Este diseño sienta las bases del sistema, aunque futuras versiones incorporarán más componentes para optimizar su rendimiento.

###  Versión 2:

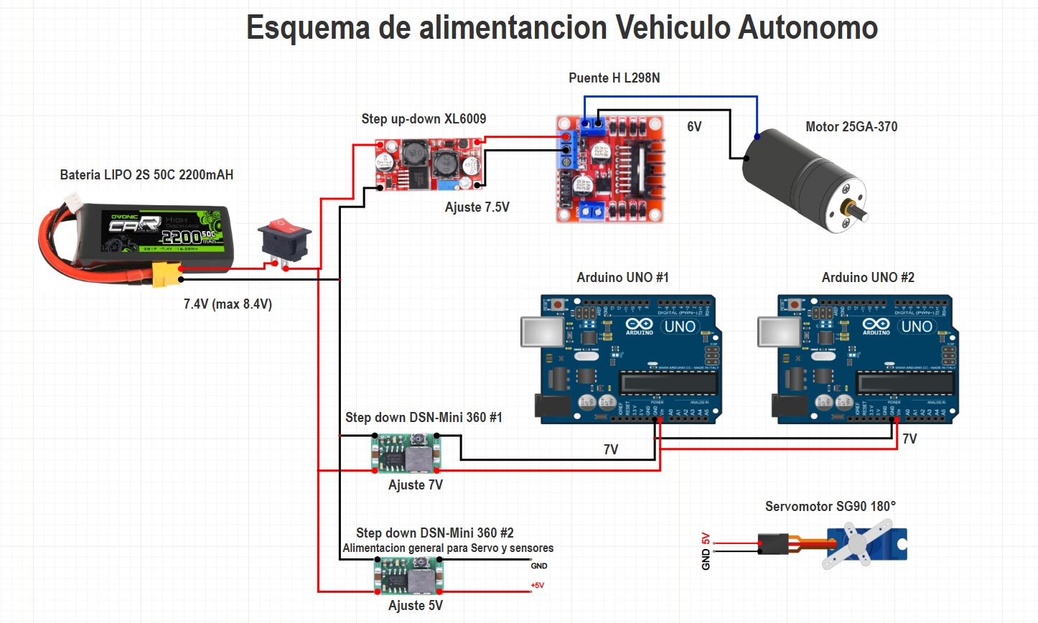
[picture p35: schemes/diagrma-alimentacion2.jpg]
Diagrama de Alimentación 2


 #### Cambios agregados a las conexiones en el sistema de alimentacion:
  1. Alimentamos ambos microcontroladores con el mismo reductor de voltaje a 7v.
  2. Agregamos un reductor de voltaje exclusivo para sensores ultrasonicos e infrarrojos y el servomotor de la direccion(que ahora se alimenta del reducctor y no del arduino).

###  Versión 3:

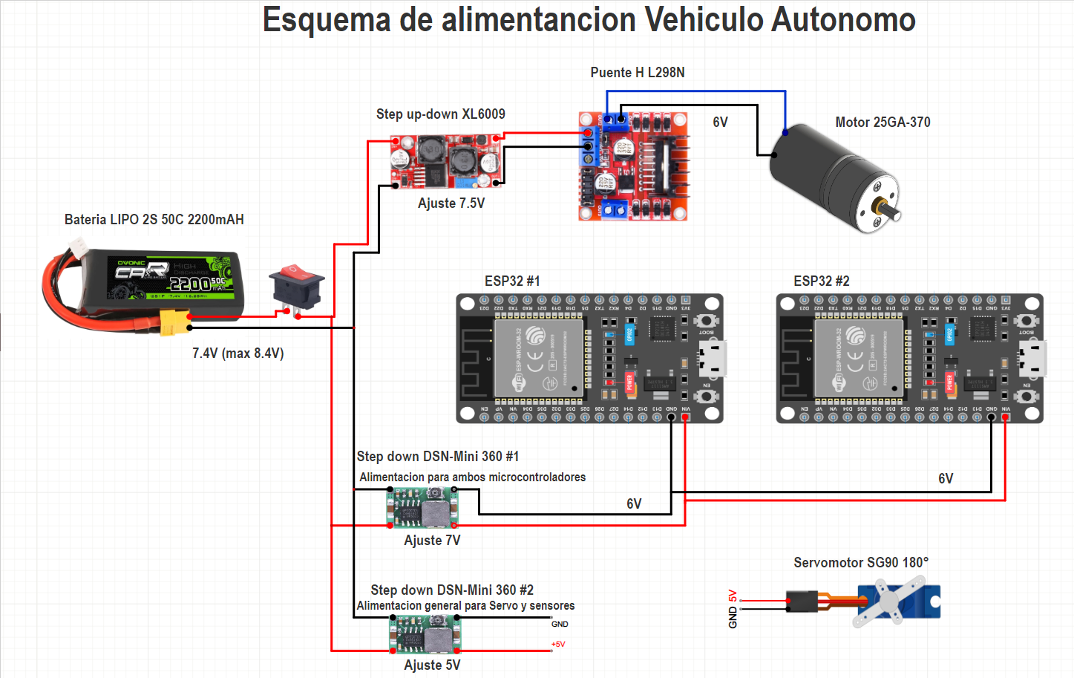
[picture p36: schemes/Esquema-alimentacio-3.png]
Diagrama de Alimentación 3


Tras la primera iteración, este diagrama detalla una revisión del sistema de alimentación del vehículo autónomo, ahora con una arquitectura que soporta más componentes y funcionalidades. 

La **batería LiPo 2S de 2200mAh** (7.4V, con un máximo de 8.4V) sigue siendo la fuente principal de energía, conectada a un interruptor general. A partir de este punto, la alimentación se ramifica: una rama se dirige a un **step-up/down XL6009** ajustado a 7.5V, que a su vez alimenta el **puente H L298N**. Este entrega aproximadamente 6V al **Motor 25GA-370** tras su caída de voltaje interna. 

De forma paralela, la batería alimenta dos módulos **step-down DSN-Mini 360**. El primero, configurado a 6V, proporciona energía a ambos microcontroladores **ESP32 #1** y **ESP32 #2**. El segundo módulo DSN-Mini 360, con un ajuste de 5V, se encarga de la alimentación general para el **Servomotor SG90 180°** y otros posibles sensores, ofreciendo una línea de voltaje estable y adecuada para estos componentes. Esta configuración ampliada permite una gestión de energía más distribuida y específica para las necesidades de cada subsistema del vehículo.

### Cálculo del Consumo Energético Total

| Componente | Cantidad | Consumo Estimado (mA) | Total (mA) |
| :--- | :---: | :---: | :---: |
| Motor DC | 1 | 500 mA (en carga) | 500 mA |
| Servo 180° | 1 | 150 mA (típico) | 150 mA |
| Sensor ultrasónico HC-SR04 | 4 | 15 mA c/u | 60 mA |
| Sensor infrarrojo Sharp | 2 | 30 mA c/u | 60 mA |
| ESP32 (sin WiFi/BT y sin carga) | 2 | ~70 mA c/u | 140 mA |
| Sensor Magnetómetro GY-273 | 1 | ~0.1 mA | 0.1 mA |
| Sensor Giroscopio/Acelerómetro MPU6050 | 1 | ~3.6 mA | 3.6 mA |
| **TOTAL** | **—** | **—** | **~913.7 mA** |

---

### 🔋 Corriente total aproximada: **~913.7 mA**

---

### ⏱️ Autonomía Estimada

**Fórmula:**
`Autonomía (h) = Capacidad de la batería (mAh) / Consumo total (mA)`

**Ejemplo con batería de 2200 mAh:**
`Autonomía ≈ 2200 mAh / 913.7 mA ≈ 2.40 horas`

> ⚠️ *Nota:* Este valor es teórico y asume un consumo constante. En la práctica, el consumo del motor puede aumentar significativamente si se encuentra con un obstáculo, por lo que la autonomía real podría variar.
---

##  ¿Porque Seleccionamos esta Fuente de Alimentacíon?

Seleccionamos una bateria LiPo (Bateria de Polimero de Litio) por su alta capacidad de almacenamiento de energía y al mismo tiem su bajo peso, en especifico nuestra bateria marca (Ovonic 2S 2200mAh 50c) donde las siglas 2S significa que la bateria es de dos celdas, cada una de ellas tiene un voltaje nominal de 3,7V, en total nuestra bateria tiene 7,4V nominales; cuando se menciona 2200mAh (Miliamperio-hora) nos referimos a la  capacidad de almacenamiento de energía de la bateria, optamos por esa cantidad de miliamperios por su rendimiento en pruebas de larga duración; y para finalizar cuando nos referimos a 50c, hablamos de la tasa de descarga de la bateria, esto nos indica la velocidad a la que la bateria puede descargarse de forma segura, en nuestro caso 50c nos permite descargar la bateria cincuenta veces su capacidad nominal.

# Sistema de Detección de Objetos

## Versión 1:

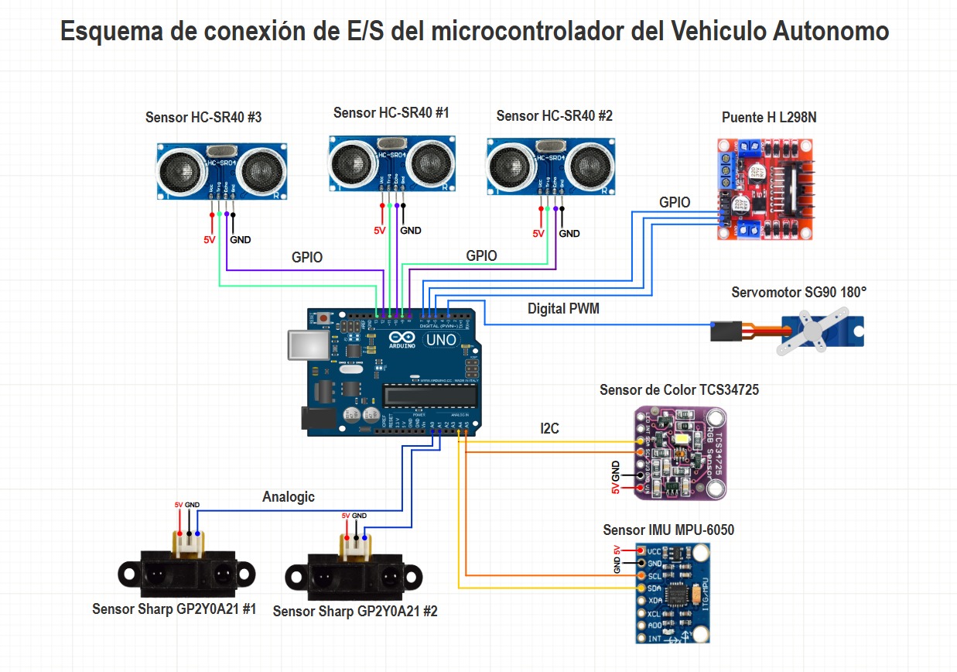
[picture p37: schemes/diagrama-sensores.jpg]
Diagrama de Sensores 1


Cada uno de los sensores instalados desempeña una función crítica para la navegación del vehículo y la prevención de colisiones:

* Los **sensores infrarrojos** se posicionan en las diagonales del vehículo, proporcionando una detección rápida y precisa para evitar obstáculos cercanos.
* Los **sensores ultrasónicos** están ubicados en la parte frontal y en los laterales, midiendo distancias para mantener un margen de seguridad con respecto a las paredes y otros objetos.
* El **sensor giroscopio** ayuda a mantener una trayectoria estable y recta, facilitando giros precisos y la orientación general del vehículo.
* El **sensor de color** se utiliza para identificar las líneas de la pista, permitiendo que el vehículo siga la ruta designada de manera autónoma.

## Versión 2: 

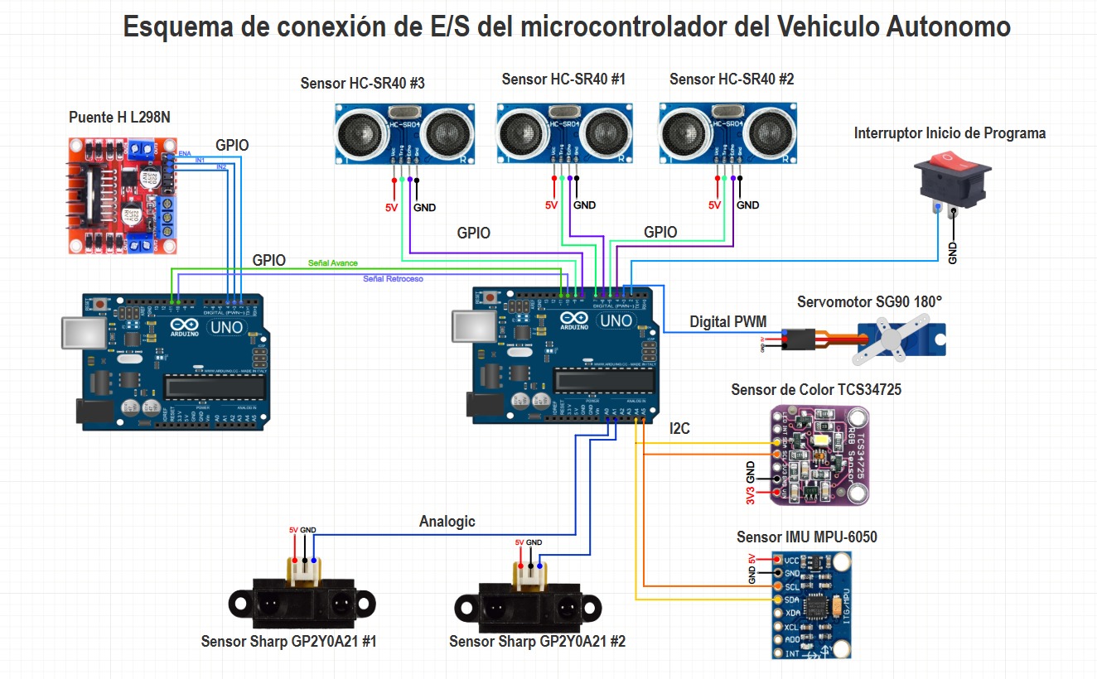
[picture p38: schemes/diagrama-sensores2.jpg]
Diagrama de Sensores


#### Mejoras implementadas en el diagrama:

1.  Se incorporó un segundo microprocesador Arduino para gestionar exclusivamente el módulo de puente H. Esta separación de responsabilidades minimiza las interferencias eléctricas y mejora el rendimiento general del sistema.
2.  Se añadió un botón de inicio para controlar la ejecución del código. Esto permite que el vehículo se encienda y realice las calibraciones iniciales de los sensores, permaneciendo en un estado de espera hasta que se active el recorrido.

## Versión 3: 

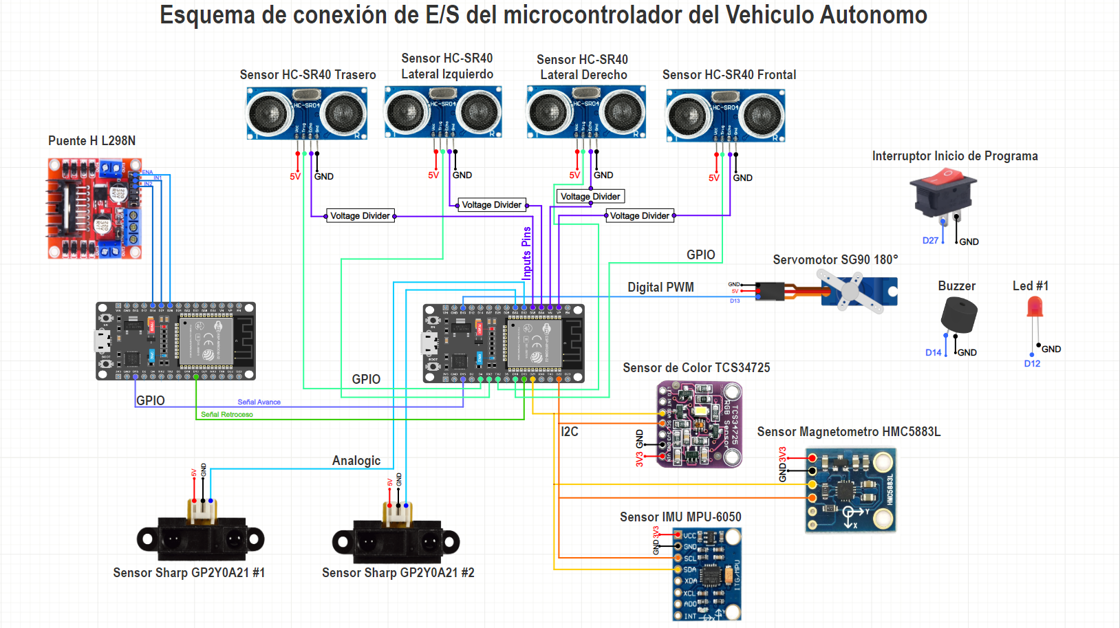
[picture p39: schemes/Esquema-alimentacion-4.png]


Esta versión representa una mejora significativa en la capacidad de procesamiento y la precisión del sistema de navegación y evasión. Los cambios más importantes incluyen:

1.  **Migración de microcontroladores:** Ambos microcontroladores Arduino fueron reemplazados por dos **ESP32**. Este cambio se hizo necesario para obtener mayor potencia de procesamiento y memoria, lo que permite ejecutar algoritmos más complejos y eficientes para la evasión de obstáculos.
2.  **Ajuste de compatibilidad de voltaje:** Se agregaron **cuatro divisores de voltaje** para los sensores ultrasónicos HC-SR04. Los pines de entrada de los ESP32 operan a 3.3V, por lo que era necesario reducir el voltaje de 5V que emiten estos sensores para evitar daños. Este ajuste de compatibilidad se detallará mas adelante.
3.  **Expansión del sistema de sensores:** Se integró un **sensor magnetómetro (HMC5883L)** para mejorar la orientación del vehículo. Los datos de este sensor, combinados con los del IMU y el resto de los sensores, ofrecen una referencia más precisa y robusta para la navegación.
4.  **Detección de obstáculos ampliada:** Se añadió un **sensor ultrasónico trasero** para mejorar la capacidad de detección y maniobrabilidad en situaciones de marcha atrás, proporcionando datos adicionales para un sistema de evasión más completo.
5.  **Sistema de notificaciones:** Se agregaron un **LED** y un **buzzer** para proporcionar indicaciones visuales y sonoras sobre el estado operativo del vehículo, como el inicio del recorrido, la detección de obstáculos o cualquier error del sistema.

Estos cambios consolidan la capacidad del vehículo para operar de manera más autónoma y segura en su entorno, basándose en un flujo de datos más rico y un procesamiento más potente.

---

### Explicación del Divisor de Voltaje para Sensores HC-SR04

Un **divisor de voltaje** es un circuito simple que permite obtener un voltaje de salida (Vout) menor a partir de un voltaje de entrada (Vin), utilizando una configuración de dos resistencias en serie. Esta solución fue esencial para adaptar la salida de 5V del pin `Echo` de los sensores HC-SR04 a la entrada de 3.3V de los pines GPIO del microcontrolador ESP32, protegiéndolo de posibles daños.

La fórmula utilizada para calcular el voltaje de salida es:

$$ V_{out} = V_{in} * (R2 / (R1 + R2)) $$

Para nuestro circuito, utilizamos los siguientes valores de resistencias:

* **R1:** 1 kΩ
* **R2:** 2 kΩ

Al aplicar la fórmula con estos valores y la entrada de 5V de los sensores, obtenemos el siguiente resultado:

$$ V_{out} = 5V * (2kΩ / (1kΩ + 2kΩ)) $$
$$ V_{out} = 5V * (2kΩ / 3kΩ) $$
$$ V_{out} \approx 3.33 V $$

Este voltaje de salida de aproximadamente 3.3V es compatible con las entradas de 3.3V del ESP32, permitiendo la comunicación segura entre el sensor y el microcontrolador.

A continuación, se muestra un esquema de conexion del divisor de voltaje simulado en tinkercad:

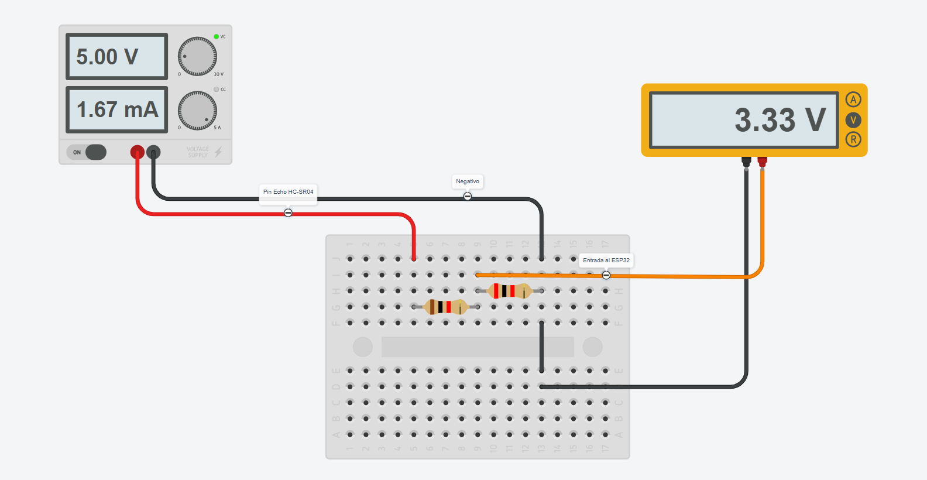
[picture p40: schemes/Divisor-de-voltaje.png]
Divisor de voltaje


---

### Implementación Física del Divisor de Voltaje

**Vista Superior:**

Esta imagen muestra la disposición de los componentes en la parte superior de la baquelita, incluyendo las resistencias de los divisores de voltaje conectadas a los pines del ESP32 y a los cables del sensor ultrasónico.

Divisores de Voltaje Vista Superior

**Vista Inferior:**

Esta imagen ofrece una perspectiva de las conexiones soldadas en la parte inferior de la baquelita, mostrando cómo se unen las resistencias para formar los divisores de voltaje y cómo se conectan los cables.

Divisores de Voltaje Vista Inferior

### Timelapse de Diseño de Circuitos

Aquí puedes observar un timelapse del proceso de diseño de los diagramas de alimentación y de las conexiones de entrada/salida de nuestros microcontroladores.

Haz clic en la imagen para ver el vídeo:

<a href="https://youtube.com/shorts/UtEvRMK07D0?si=VvvrS2JtITUjtCgx" target="_blank">
  Miniatura del Video Timelapse de Diseño de Circuitos
</a>

---

##  Paso a Paso de la Construcción

### Etapa de Diseño y Ensamblaje del Vehículo

El diseño de nuestro vehículo comenzó con un **modelo 3D en Tinkercad** para definir las dimensiones y el tamaño de cada componente. Este modelo se concibió para un vehículo de dos plantas:

* **Planta Baja:** Aloja el sistema de transmisión, sistema de dirección, motor, sistema de potencia y sensores (frontales, laterales y diagonales).
* **Segundo Piso:** Contendrá el Arduino y la cámara (originalmente no se pensó en un teléfono celular, pero se consideró la idea en esta etapa). La imagen muestra cómo un teléfono celular interactuaría con nuestro vehículo.

| Vista Frontal | Vista Base | Vista Lateral |
| :---: | :---: | :---: |
| Modelo 3D Frontal | Modelo 3D Base | Modelo 3D Lateral |

### Montaje del Vehículo

| Imagen | Descripción |
| :----: | :--- |
| Molde Base | Aquí se muestran algunas medidas ya probadas para las primeras pruebas del coche. Utilizamos cartón como material de prueba para realizar cambios sin incurrir en costos adicionales. La base se cubrió con una doble capa de cartón para mayor rigidez. |
| Instalación de Transmisión | Colocamos la transmisión LEGO en la base y realizamos los cortes necesarios para que el motor, la dirección y la transmisión encajaran correctamente. Luego, instalamos el servomotor en el diferencial y el motor DC en la transmisión. |
| Instalación de Servo | Encaje del servomotor con el sistema de direccion. |
|  Instalación de Motor DC | Encaje de motor dc con el sistema de transmision. |
| Primera Estructura | Con todos los elementos esenciales ensamblados, conectamos el motor a la alimentación con el regulador para una prueba de funcionamiento rápida, verificando el correcto desempeño del motor y la transmisión. |

### Diseño de base 3d
Teniendo en cuenta el modelo diseñado en carton empezamos con la modelacion en 3d de nuestro vehiculo para construirlo con un material mas resistente que no sufra los defectos de nuestra primera base de carton.

| Imagen | Descripción |
| :----: | :--- |
| diseño de la base | Empezamos realizando el primer piso en base a las medidas que teniamos previamente, en el software de Tinkercad. |
| diseño de la base | En nuestro primer piso realizamos la base donde encajara nuestro motor, para ello realizamos un agujero con el diametro del motor, y un pequeño espacio para la union de los ejes. |
| Montaje de la Nueva Base 2| Luego de ya tener fijado nuestro motor empezamos a diseñar y probar el espacio en donde encajaria el soporte para nuestro servomotor. Ademas agregamos el soporte para nuestros soportes hexagonales. |
| diseño de la base | Por debajo del vehiculo realizamos el espacio para nuestro sensor de color (posteriormente se cambio de posicion para optimizar el rendimiento del vehiculo).  |
| Montaje de la Nueva Base 4 | Empezamos a probar el segundo piso con las mismas medidas del piso de abajo y la altura que habria entre los dos pisos. |
| diseño de la base | En el segundo piso realizamos los espacios para los tornilos que fijarian los separadores hexagonales al segundo piso. Ademas se hicieron espacios para el interruptor de encendido y espacio para fijar la bateria y el dispositivo movil mediante precintos de seguridad. |
| diseño de la base | A nuestro segundo piso le agregamos una pequeña base para nuestro medidor de voltaje. |
| diseño de la base | Volviendo a nuestro primer piso realizamos medidas con nuestros componentes y terminamos de arreglar algunos detalles. |
| diseño de la base | Primer y segundo piso ya armados con su respectiva separación. |
| diseño de la base | Agregamos un aleron al diseño como toque estetico. |
| diseño de la base | Vista final de como quedo todo el diseño 3d. |
| diseño de la base | Exportamos nuestro diseño a Fusion 360, para trabajar con mas precision y agregar las tolerancias para realizar la impresion 3d. |
| diseño de la base | Terminamos de trabajar con las tolerancias respectivas y haber confirmado todas las medidas. | 
| diseño de la base | Debajo del vehiculo redondeamos el sobresaliente de la base de nuestro motor para darle un toque mas estetico y funcional. |
| diseño de base | Luego de terminar todos estos ajustes procedimos a exportar cada parte del diseño de forma independiente en un formato (STL). |
| Montaje de la Nueva Base 4 | Y aca podemos observar los resultados finales de la impresión 3d. |

---

## Cambio de Base

| Imagen | Descripción |
| :----: | :--- |
| Montaje de la Nueva Base | Inicio del proceso de cambio de base del prototipo hecho en carton a nuestra impresion 3d y pequeña modificacion en el primer piso de nuestro vehiculo. |
| Montaje de la Nueva Base 2 | Aca podemos observar la colocacion del sistema de dirección y tracción trasera. |
| Montaje de la Nueva Base 3 | Empezamos a realizar todo el cableado de algunos componentes. |
| Montaje de la Nueva Base 4 | Se continúa con el ensamblaje de la nueva base. |

### Mejoras en el orden de los cables y componentes (Segundo Prototipo - Base 3D)

Tras el cambio a la base impresa en 3D, realizamos una mejora significativa en el cableado y la organización interna de nuestro segundo prototipo para optimizar su rendimiento y estética.

Haz clic en la imagen para ver el vídeo:

<a href="https://www.youtube.com/shorts/rl1eokkc18E" target="_blank">
  Miniatura del Video de Mejora de Cableado
</a>

### Reubicación, mejoras y modificaciones (Tercer Prototipo)

A continuación, se detallan las modificaciones y mejoras implementadas en la tercera versión del prototipo.

#### 1. Reubicación de sensores y mejoras en el cableado

Para esta nueva versión, se realizó un reajuste estratégico en la posición de varios sensores clave, buscando mayor comodidad y eficiencia. Esto incluyó el reposicionamiento de los sensores de ultrasonido frontales, los sensores Sharp y el sensor de color, que fue desplazado hacia la parte delantera. Adicionalmente, se optimizó el cableado superior para adaptarlo a la nueva configuración de dos microcontroladores ESP32 y la integración de un magnetómetro. Finalmente, se reforzó la base del primer piso mediante el uso de tornillos inferiores para una mayor estabilidad.

Descripción de la imagen

#### 2. Modificaciones en la base para el nuevo soporte de teléfono

Inicialmente, para validar el concepto y realizar las primeras pruebas de campo, se diseñó una adaptación provisional utilizando un material de goma espuma plástica. Este prototipo inicial nos permitió evaluar la funcionalidad del soporte de manera rápida y económica. Una vez comprobada su viabilidad, se procedió a diseñar e implementar la solución definitiva, que consistió en la integración de un trípode adaptado a la base del robot.

Como se mencionó anteriormente al mejorar nuestra app y su sistema de detección de objetos ahora debíamos mejorar el soporte de nuestro teléfono, para ello se diseñó e implementó una solución para el posicionamiento elevado del teléfono encargado del análisis de imágenes en tiempo real. La base de esta solución fue un trípode de teléfono convencional, el cual fue sometido a un proceso de modificación estratégica para su integración en el chasis del vehículo.

El procedimiento inicial consistió en un desmontaje selectivo, eliminando componentes innecesarios como las patas extensibles, para conservar únicamente los elementos funcionales: el soporte de sujeción del dispositivo y su vástago o columna central. El objetivo principal era posicionar el teléfono en una orientación horizontal y a una altura estratégica, garantizando así que la cámara tuviera un campo de visión amplio. Esta configuración es crucial, ya que permite al sistema capturar simultáneamente información tanto de los objetos que se encuentran delante como de aquellos que se encuentra por detrás, lo que representa una mejora significativa y un requisito indispensable para la fiabilidad de nuestro nuevo sistema de navegación.

Una vez finalizada la fase de planificación, procedimos con la operación de montaje. Para adaptar e integrar el soporte al vehículo, se realizó una perforación de precisión en la base de la plataforma superior. Dicho orificio fue dimensionado específicamente para alojar el diámetro del vástago del trípode, asegurando un encaje firme. Posteriormente, se fijó sólidamente la estructura y se realizaron diversas pruebas de ajuste y resistencia para validar la solidez del montaje. Se llevaron a cabo ensayos de vibración y estabilidad para comprobar que el soporte permanecería estático durante el desplazamiento del vehículo, garantizando así una navegacion segura y un funcionamiento correcto del sistema de análisis de imagenes que implementa nuestra app.

| Imagen | Descripción |
| :----: | :--- |
| Modificación al tripode | Se modifico el tripode antes de ser instalado en la base del vehículo, de maneras que se descartaron las partes innecesarias para la adaptacion como lo son el mango de agarre y las patas de apoyo. |
| Marca para la Perforación | Aquí se puede observar la marca en las medidas necesarias para la perforación de la base del vehículo, para así poder adaptar este tripode modificado. |
| Perforación hecha | Se puede observar el resultado luego de que se hiciera la perforación que permitira la instalación del tripode. |
| Finalizacion de la instalacion del tripode | Se busco una posición optima para posicionar el tripode, de manera que pudiera tener un mejor angulo de visión, lo que permitira mejorar la visibilidad de los obstaculos en pista. Luego se procedio a fijar dicho tripode a la base superior del vehículo con una combinación de quimicos que permitira una fijación optima. |

---

## Problemas encontrados. 

### interferencia con el puente H, solución: Un sistema maestro y esclavo.

Al momento de realizar las pruebas de vueltas a la pista nos percatamos que el vehículo no respondía correctamente y al momento de realizar a el giro nunca terminaba de realizarlo o simplemente no detectaba la línea y por esto no lo realizaba. Entre mucha investigación encontramos que la falla era una interferencia con los pines que mandaban las señales al modulo de puente H. Por lo que buscamos aislar estos cables resultando sin éxitos. 
La solución probada fue conectado un segundo microcontrolador Arduino esclavo, encargado exclusivamente de enviar los comandos de avanzar, retroceder, detenerse y algún cambio de velocidad al módulo puente H, mientras que el Arduino principal en este caso el maestro, llevara todos los sensores y cables conectados al esclavo para indicarle que acción debe ejecutar el puente H. 
De esta manera logramos distanciar esta interferencia y el código fluía continuamente sin problemas

#### Diagrama del codigo del microcontrolador arduino esclavo.

Diagrama del codigo del arduino esclavo

---

## Pruebas Realizadas

### Prueba del Sensor de Color

Haz clic en la imagen para ver el vídeo:

Mira el video del proyecto (https://youtu.be/7GS6mCXmGks)

### Fabricacion de pista a escala

Para las pruebas, creamos una imitación de la pista de competición utilizando láminas recicladas, pegadas para cumplir con los estándares de 3x3 metros. Nuestra pista tiene un ligero error de aproximadamente 10 cm. Las esquinas de la pista deben tener dos líneas, una azul y otra naranja, separadas por 30 grados cada una, tomando el mismo origen que la esquina interior del cuadrado.

Pista de Pruebas

## Desarrollo de la Logica del codigo Maestro

### Funcion actualizarGiro():

  Para hacer que el vehiculo estuviera siempre guiado usamos la funcion actualizarGiro(), con ella simulamos un brujula digitar.

Esta función es un sistema de fusión de sensores que combina dos fuentes de datos para obtener el ángulo final del vehículo: el MPU6050 (giroscopio) y el magnetómetro (a través de obtenerAngulo()).

  El giroscopio mide la velocidad de rotación del vehículo (qué tan rápido está girando). La función toma esta velocidad y la suma a un ángulo acumulado (anguloZ) en cada ciclo de lectura. Piensa en esto como un cálculo continuo del ángulo de giro. Es muy preciso a corto plazo, pero tiene un problema: la deriva (pequeños errores que se acumulan con el tiempo).

 Para solucionar la deriva del giroscopio, la función llama a obtenerAngulo(), Esta función es el corazón del sistema, actúa como un compás digital usando el sensor QMC5883L (magnetómetro).

### Funcion obtenerAngulo():

 Se conecta con el magnetómetro y lee los valores magnéticos en los ejes X, Y y Z. Estos valores representan la intensidad del campo magnético de la Tierra. Utiliza los valores X e Y para calcular el ángulo en un plano 2D, de forma similar a cómo lo haría una brújula. Este ángulo es la dirección del vehículo con respecto al Norte magnético. Se aplican correcciones (xOffset, yOffset, declinacionMagnetica) para mejorar la precisión y compensar la ubicación geográfica.

  En la primera lectura válida, la función toma el ángulo absoluto actual y lo define como el punto de referencia (0°). Esto significa que la dirección en la que mira el vehículo al encenderse se considera su punto de partida.

 Todas las lecturas subsiguientes se comparan con ese ángulo de referencia inicial. El resultado es el ángulo relativo del vehículo con respecto a su dirección inicial, que es el valor que finalmente devuelve la función.

 El ángulo del magnetómetro es absoluto y no tiene deriva, pero es más susceptible a interferencias externas (como metales o campos magnéticos).

### Fusión de los datos

Aquí es donde ocurre la magia. La función compara el ángulo calculado por el giroscopio con el ángulo de referencia del magnetómetro. La diferencia entre ambos valores se usa para corregir suavemente el ángulo del giroscopio, ajustándolo hacia el valor más confiable del magnetómetro. El ajuste es gradual (* 0.1) para evitar saltos bruscos en la lectura.

Esta combinación aprovecha lo mejor de ambos mundos: la velocidad del giroscopio para detectar movimientos instantáneos y la precisión del magnetómetro para mantener el ángulo sin errores a largo plazo.
## Logica de vueltas a la pista

Para este momento ya teníamos idea de la lógica de nuestro primer código del primer desafío que seria la vuelta libre a la pista. En esta lógica usaremos las líneas de la pista para marca el momento exacto para cruzar y el conteo de vueltas siendo 4 líneas igual a una vuelta y así cumplir las 3 vueltas que serían 12 líneas, con el sensor giroscopio(mpu6050) mediremos los grados que va girando el vehículo para calcular exactamente los 90grados del cruce de la esquina. Un planteamiento básico que nos sirvió como comienzo. A partir de aquí presentamos los siguientes problemas. 
•	Falta de detección de líneas: Con el sistema de detección de color tuvimos problemas para detectar las líneas ya que había veces que no la detectaba por la velocidad del vehículo por lo que aumentamos la tasa de refresco a :
Adafruit_TCS34725 tcs = Adafruit_TCS34725(TCS34725_INTEGRATIONTIME_2_4MS, TCS34725_GAIN_1X);
INTEGRATIONTIME _2_4MS es el tiempo de integración, que es el tiempo que la carama recoge luz para hacer una lectura y el Gain_1X es la ganancia que es un factor de amplificación que se aplica a la señal de los fotodiodos antes de la conversión analógica a digital.

•	Sobre detección y detección errónea: Detectaba la línea más de una vez y en algunas zonas por la diferencia de luz podía tomar un color distinto como azul o naranja, por lo que desarrollamos una lógica que saca el promedio de las ultimas 3 mediciones para garantizarnos que si era la línea azul y que no tomara el comando mas de una vez.

•	Desviación: Luego se utilizó un sistema de centrado con 2 sensores ultrasónicos laterales para corregir el problema de que el vehículo no quedaba exactamente con 90 grados al momento después de terminar el cruce. Este sistema compara ambas distancias e intenta mover el servomotor para que cruce en dirección al lado con mayor distancia. Esto luego fue robustecido con un sistema PID que hace correcciones diferentes según el nivel de desviación para una corrección leve si la desviación es poca o fuerte si es grande. 
El ángulo de cruce que el mpu suma al ángulo actual fue modificado de 90 a 70 ya que el sensor giroscopio cuando llegaba su medición a 90 grados el vehículo cruzaba de más por lo que fuimos calibrando manualmente este valor hasta 70 grados con el que el vehículo se logró desempeñar mejor en las pruebas. Este valor puede ser distinto dependiendo de la calibración o posición de montaje del sensor por eso es mejor calibrarlo cada quien en sus montajes mediante las pruebas.

Para culminar con este código realzamos la lógica necesaria para cumplir con la condición de que el vehículo girara en ambos independientemente (horario y antihorario). Por lo que pensamos en una lógica para que el vehículo dependiendo de la línea que se encontrase primero sería el sentido de la vuelta si es azul es horario y si es naranja es antihorario. Para la lógica de antihorario seria restar 70 grados al ángulo actual y girar a la izquierda en lugar de la derecha como en la lógica pasada. 

### Diagrama de logica de vueltas a la pista.
 Diagrama del codigo de vueltas a la pista

### Diagrama de logica PID del centrado y giro.
 Diagrama del codigo de vueltas a la pista

## Desarrollo de la logica de evasion de objetos.

### Primer esquive:
Ya con app lista desarrollamos una lógica para el microcontrolador Arduino y de esta manera recibir los comandos de color del objeto y su distancia. Realizando una prueba controlada tuvimos unos errores con la iluminación que nos afectaba el reconocimiento de los colores por que tuvimos que ajustar los valores de los colores para mejorar la detección del objeto que termino siendo mejor pero todavía le faltan mejoras, pero cumplió con el objetivo de identificar el objeto y darnos su distancia aproximada, que a 30 cm el Arduino deberá realizar el giro a la derecha si es rojo(R) y a la izquierda si es verde(G), con un retorno al lado contrario luego de realizar el giro para reincorporarse al centro del carril de la pista. 

   ### Orientacion hacia el objeto para posterior esquive.
Problema: El vehículo cuando no está perfectamente en dirección al objeto este ejecutara el esquive pero lo derribara o simplemente perderá de vista el objeto ya que su dirección no va hacia el, por tal razón pensamos en una lógica para que dependiendo de la posición del objeto en la cámara de la del teléfono mandara comandos como C(centro), D(derecha) y I(izquierda), de esta manera ir moviendo de forma controlada la dirección según el comando recibido apenas se capte el objeto en la visión de la cámara. Con este cambio realizado el vehículo se posiciona de manera adecuada frente al objeto a esquivar y realiza su movimiento preciso para esquivar durante 1 segundo y al retornar al centro durante 1 segundos.

Problema: al momento de retornar al centro puede que haya un objeto fuera de ranga de la cámara por que al momento de esquivar si se veía pero este modo no es capaz de comenzar el seguimiento así que se le agregó que si detecta otro objeto mientras este en modo de retorno cambie a modo de seguimiento nuevamente. Ademas se le aumento el modo de retorno para que haga un mapeo al area por si no llega a identificar un objeto.

Aquí dejo el paso a paso de la realización de la app:

### Diagrama de logica de evasion de objetos
 Diagrama del codigo de evasion de objetos

# Desarrollo de Códigos Combinados

---

## Para este momento necesitamos una lógica que nos permita:

1.  **Un botón de inicio:** Un botón que energice el vehículo y programe el inicio del código al enviar una señal.

2.  **Detección y conteo de líneas:** Girar en la dirección correcta al detectar una línea y llevar el conteo de las mismas para saber las vueltas.

3.  **Recepción de comandos de la app:** Recibir comandos de la aplicación cuando se detecta un objeto en la pista, incluyendo su color y posición.
    * **Orientación:** Orientarse para quedar al frente del objeto.
    * **Esquive:** Esquivarlo dependiendo de su color (Rojo por derecha, Verde por izquierda).

4.  **Centrado del vehículo:** Centrar el vehículo según las paredes exteriores cuando no esté recibiendo comandos de objetos detectados.

5.  **Estacionamiento:** Estacionarse en paralelo en el área indicada al final del recorrido.

---

## Con nuestros objetivos claros, desarrollamos una máquina de estados capaz de abarcar todo lo requerido y cambiando de estado según las condiciones impuestas:

### ESTADO_NORMAL $\leftrightarrow$ SIGUIENDO_OBJETO $\leftrightarrow$ ESQUIVANDO

---

### ESTADO_NORMAL:

En este modo abarcamos todos los objetivos del código 1 de vueltas a la pista, donde detectamos las líneas que nos indican el cruce. Mientras no estemos evadiendo objetos, estamos centrando el vehículo dependiendo de la distancia con las paredes laterales. Además, añadimos la recepción de comandos de la aplicación para indicarnos que hay un objeto, lo cual nos hace cambiar al estado "SIGUIENDO_OBJETO".

* **Navegación básica siguiendo líneas:**
    * Detección de líneas de colores (azul/naranja).
    * Centrado automático en el pasillo usando sensores ultrasónicos.
* Recepción de comandos de la aplicación.

#### Transiciones:

* **A SIGUIENDO_OBJETO:** Cuando recibe el comando 'R' o 'G' por la aplicación.
* Permanece en estado hasta nueva detección.

---

### SIGUIENDO_OBJETO:

En este estado, orientamos la dirección del vehículo con el servomotor en función de los comandos recibidos por la aplicación, ya sea a su orientación izquierda (I), derecha (D) o centro (C). Cuando se detecta que el comando de distancia del objeto es menor o igual a 30 cm, se realizará el cambio al estado "ESQUIVANDO". Si el objeto se pierde de vista por alguna razón, volveremos al estado "NORMAL".

* Orienta el servo según la posición del objeto detectado.
* Mantiene el motor activo para seguir el objetivo.
* Procesa la orientación del objeto (Izquierda/Derecha/Centro).

#### Transiciones:

* **A ESQUIVANDO:** Cuando el objeto está muy cerca ($\le 30 \text{cm}$).
* **A ESTADO_NORMAL:** Cuando pierde el objeto (comando 'N').

---

### ESQUIVANDO:

* Ejecuta la secuencia de esquive en 6 etapas:
    * **Case 0: Orientación inicial (300ms):** Servo hacia el lado de esquive.
    * **Case 1: Preparación (tiempo variable):** Activación del motor.
    * **Case 2: Esquive activo (1200ms):** Avance lateral evitando el obstáculo.
    * **Case 3: Reorientación interrumpible (300ms):** Giro hacia el lado contrario para retorno.
    * **Case 4: Retorno interrumpible (3000ms):** Avance de vuelta al curso original.
    * **Case 5: Finalización (100ms):** Centrado y retorno al estado normal.
* Los "Case 3" y "Case 4" son interrumpibles si se detecta un objeto mientras se está retornando para cambiar al estado "SIGUIENDO_OBJETO".

#### Transiciones:

* **A SIGUIENDO_OBJETO:** Durante las etapas 3-4 si detecta un nuevo objeto.
* **A ESTADO_NORMAL:** Al completar la secuencia de esquive.

## Cambio de logica de esquive version 2.0 sistema de carriles.

  ### Funcion realizarGiro():
  Para este momento nos imaginamos un caso mejor donde el esquive fuera mas preciso, anteriormente esabamos implementardo un sistema para girar que consistia en que el vehiculo dependiendo de la distancia lateral giraba mas o menos para luego aplicar un retroceso post giro a ciegas. Esto era ineficiente por que a ciencia cierta nunca sabremos donde terminara el vehiculo por lo que ahora ese retroceso post giro sera controlado por el angulo llegando a un angulo recto dependiendo del conteo de lineas que lleve y el sentido del vehiculo todo gracias a la funcion actualizarGiro que nos proporciona el angulo, un ejemplo de ello con fragmento del codigo:

calculo_angulo_retroceso

Ahora que nos posicionamos siempre en un angulo correcto el vehiculo puede retroceder y con el sensor ultrasonico trasero determinar una distancia suficiente para proceder con los esquives.

### Explicacion de la nueva logica:
Ahora en lugar de hacer un mismo metodo de esquive para cualquier objeto que identifiquemos haremos un nuevo metodo, gracias a la mejora de la aplicacion podemos identificar 2 objetos a la vez y sus posiciones por lo que dependiendo se como sea la configuracion de los mismos podremos hacer un esquive programado indepediente y unico, de esta manera nos aseguramos de tomar cada caso por separado y con mayor eficacia. 

### Máquina de Estados para Navegación por Carriles
La lógica del vehículo se gestiona mediante una máquina de estados que transita entre diferentes modos operativos. Este sistema reemplaza el antiguo modelo de "Seguir/Esquivar" por uno más adecuado para la navegación en pista.

ESTADO_NORMAL ↔ ESPERANDO_COMANDO_CARRIL → EVALUANDO_POSICION → GIRANDO_HACIA_CARRIL → MANTENIENDO_CARRIL

#### ESTADO_NORMAL:
Este es el estado inicial y el modo por defecto después de completar un giro en una intersección.

Avanza en línea recta mientras utiliza la función centrarVehiculo() para mantenerse estable en el pasillo con una vigilancia activa, su objetivo principal es buscar la siguiente línea de color con la función detectarColor(). Al encontrar una, inicia la secuencia de giro (realizarGiro) y el ciclo de navegación se repite.

##### Transición: Si no detecta una línea, puede pasar a ESPERANDO_COMANDO_CARRIL después de la maniobra post-giro.

### ESPERANDO_COMANDO_CARRIL:
En este estado, el vehículo se detiene y espera instrucciones externas.

El motor se apaga y el sistema monitorea activamente el puerto serie para recibir un comando de carril.

#### Transición: Al recibir un comando válido, cambia a EVALUANDO_POSICION.

### EVALUANDO_POSICION:
Estado de transición muy breve para planificar el cambio de carril.

Lee los sensores ultrasónicos laterales para determinar su posición actual en relación con el carril objetivo. Decide la dirección del giro necesario para alcanzar el nuevo carril.

#### Transición: Inmediatamente cambia a GIRANDO_HACIA_CARRIL.

### GIRANDO_HACIA_CARRIL:

 Aqui aplicaremos una nueva logica donde dependiendo de las distancias laterales nos dameremos cuenta en que parte de la pista nos encontramos, dividiendo la pista en 2 carriles principales y 2 secundarios. Los principales son:
 1. Carril 1: A la derecha del vehiculo. Usado para los objetos rojos.
 2. Carril 2: A la izquierda del vehiculo. Usado para los objetos verdes.
 3. Carril 1 pero a mas distancia de la pared
 4. Carril 2 a mas distancia de la pared.
Dependiendo de que objeto tengamos al frente tomaremos un carril. Hay doble objeto se ejecuta un cambio de carril apenas se consiga entrar en el estado donde mantiene el carril, esto se hace de la misma manera que se dirige al carril en un inicio solo que un poco mas de tiempo. este tiempo depende del comando en especifico.

#### Posicionamiento en un carril:
Dependiendo de a que carril deseemos dirigirnos usaremos diferentes sensores:
  Carril 1: Sensores derechos Ultrasonico e infrarrojo.
  Carril 2: Sensores izquierdos Ultrasonico e infrarrojo.
  
Para realizar el posicionamiento recurrimos al estado GIRANDO_HACIA_CARRIL, donde mediantes algunas funciones tendremos un giro hacia el carril correspondiendo con cierta inclinacion de la direccion y un tiempo establecido que dependen de la distancia lateral que alla con la pared externa de la pista. Al finalizar pasaremos a un giro de retorno en sentido contrario que terminara cuando el angulo sea recto. 

Durante el primer giro estaremos esperando de igual manera una retroalimentacion del sensor sharp correspondiente para que nos confirme si estamos a una buena distancia de la pared lateral, si estamos muy cerca interrumpira el primer giro dara un breve retroceso y procedera con el giro de retorno. 

#### Transición: Una vez que el vehículo está orientado en el nuevo carril, cambia a MANTENIENDO_CARRIL.

### MANTENIENDO_CARRIL:
Este es el estado de navegación principal entre intersecciones.

Utiliza un controlador PID para mantener de forma activa y precisa la distancia con la pared lateral (izquierda o derecha, según el carril). Esto le permite seguir el contorno de la pista con gran exactitud.

Control Fino: El sistema prioriza mantener el ángulo correcto; si el vehículo se desvía demasiado, corrige primero su orientación y luego ajusta la distancia a la pared.

#### Transición: Permanece en este estado hasta que detectarColor() encuentra una línea, lo que interrumpe el mantenimiento del carril e inicia un giro de intersección, devolviendo el sistema al ESTADO_NORMAL.

### ESTADO_DETENCION_FINAL:
El estado final del recorrido. Se activa después de que se cuenta la última línea y se completa el último giro. El vehículo avanza en línea recta durante un tiempo predefinido (1.5 segundos) para posicionarse en la zona de estacionamiento.

#### Transición: Al finalizar el avance, llama a detenerRobot() para apagar todos los motores y finalizar la operación.
 
 ### Diagrama logica de esquive 2.0 sistema de carriles
 Diagrama de logica carriles
## Video resumen de las pruebas de vuelta a la pista y esquive de objetos.

Haz clic en la imagen para ver el vídeo:

Mira el video del proyecto (https://youtu.be/E-xsGcDSaJY?si=9i87w-iJ8TijE_ca)

## Prueba de vueltas a la pista

Haz clic en la imagen para ver el vídeo:

Mira el video del proyecto (https://youtube.com/shorts/wI_OLS1nWhc?si=868zlHss_CnnXe10)

## Prueba de evacion de obstaculos

Haz clic en la imagen para ver el vídeo:

Mira el video del proyecto (https://www.youtube.com/watch?v=WQM6CjVKSwE)

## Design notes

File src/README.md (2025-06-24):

# Software del Vehículo Autónomo WRO Prometheus

## Código del Microcontrolador (Arduino)

El software del microcontrolador para nuestro vehículo autónomo ha sido desarrollado utilizando el IDE de Arduino. Este código gestiona la interacción directa con los sensores y actuadores del vehículo.

### Librerías del Proyecto Arduino

El proyecto de Arduino utiliza las siguientes librerías. Para asegurar una compilación exitosa, es fundamental que estas librerías estén instaladas en tu IDE de Arduino.

* **`Wire.h`**:
    * **Tipo**: Librería estándar de Arduino.
    * **Descripción**: Permite la comunicación a través del bus I2C (Inter-Integrated Circuit), fundamental para interactuar con sensores como el TCS34725 y el MPU6050.
    * **Instalación**: Viene preinstalada con el IDE de Arduino. No se requiere acción adicional.
    * **Documentación**: [Referencia de la Librería Wire (Arduino)](https://docs.arduino.cc/language-reference/en/functions/communication/wire/)

* **`Adafruit_TCS34725.h`**:
    * **Tipo**: Librería externa (Adafruit).
    * **Descripción**: Controla el sensor de color TCS34725, permitiendo la lectura de valores RGB para la detección de colores en el entorno.
    * **Instalación**: Se instala a través del **Gestor de Librerías del IDE de Arduino** buscando "Adafruit TCS34725".
    * **Documentación**: [Repositorio de GitHub de Adafruit_TCS34725](https://github.com/adafruit/Adafruit_TCS34725) | [Overview de Adafruit sobre TCS34725](https://learn.adafruit.com/adafruit-color-sensors/overview)

* **`MPU6050.h`**:
    * **Tipo**: Librería externa (Electronic Cats).
    * **Descripción**: Facilita la interacción con el giroscopio y acelerómetro MPU-6050, proporcionando datos de movimiento y orientación para la navegación del vehículo.
    * **Instalación**: Se instala a través del **Gestor de Librerías del IDE de Arduino** buscando "MPU6050" (by Electronic Cats).
    * **Documentación**: [Repositorio de GitHub de MPU6050 Electronic Cats](https://github.com/ElectronicCats/mpu6050)

* **`Servo.h`**:
    * **Tipo**: Librería estándar de Arduino.
    * **Descripción**: Permite controlar motores servo, utilizados para movimientos precisos en el vehículo (por ejemplo, dirección o manipulación).
    * **Instalación**: Viene preinstalada con el IDE de Arduino. No se requiere acción adicional.
    * **Documentación**: [Referencia de la Librería Servo (Arduino)](https://www.arduino.cc/reference/en/libraries/servo/)

* **`ColorConverterLib.h`**:
    * **Tipo**: Librería externa.
    * **Descripción**: Utilizada para la conversión entre diferentes espacios de color (ej. RGB a HSV/HSL), optimizando el procesamiento y la interpretación de los datos del sensor de color.
    * **Instalación**: Esta librería puede no estar disponible directamente en el Gestor de Librerías de Arduino. Se recomienda descargarla desde su repositorio de GitHub. Para instalarla, descargue el archivo ZIP y añádalo a su IDE de Arduino (`Sketch > Incluir Librería > Añadir Librería .ZIP`).
    * **Documentación/Repositorio**: Puedes encontrar el código fuente y más detalles en el repositorio oficial de GitHub: **[Arduino-ColorConverter](https://github.com/luisllamasbinaburo/Arduino-ColorConverter/tree/master)**

---

### Preparación del Proyecto Arduino

Para cargar el código en el microcontrolador de su vehículo:

1.  **Requisitos Previos**:
    * Tenga instalado el **IDE de Arduino** en su computadora.
    * Asegúrese de haber instalado todas las librerías externas mencionadas (Adafruit_TCS34725, MPU6050, ColorConverterLib) a través del Gestor de Librerías de Arduino o manualmente según sea necesario.

2.  **Abrir el Proyecto**:
    * Abra el archivo `.ino` principal de su proyecto de Arduino en el IDE de Arduino.

3.  **Seleccionar Placa y Puerto**:
    * En el IDE de Arduino, vaya a `Herramientas > Placa` y seleccione el modelo de Arduino que está utilizando (ej., Arduino Uno, ESP32 Dev Module, etc.).
    * Luego, vaya a `Herramientas > Puerto` y seleccione el puerto serie al que está conectado su Arduino.

4.  **Verificar y Subir**:
    * Haga clic en el botón "Verificar" (el checkmark) para compilar el código y comprobar errores.
    * Una vez verificado, haga clic en el botón "Subir" (la flecha) para cargar el código a su microcontrolador Arduino.

---

## APP WRO Prometheus Desarrollada en Android Studio

Este directorio contiene el código fuente y los artefactos necesarios para la aplicación **WRO Prometheus**, que sirve para procesar datos de imágenes para nuestro Vehículo Autónomo en la competencia. Aquí encontrarás toda la información relevante sobre las tecnologías utilizadas y cómo preparar el proyecto.

---

### Tecnologías y Dependencias Principales

Nuestra aplicación Android ha sido desarrollada utilizando **Android Studio** y se basa en las siguientes librerías y marcos de trabajo:

#### Librerías de AndroidX y Material Design

Componentes fundamentales de la plataforma Android para la interfaz de usuario y funcionalidades básicas, asegurando compatibilidad y una experiencia de usuario moderna.

* `androidx.core:core-ktx`: [Documentación oficial de AndroidX Core KTX](https://developer.android.com/kotlin/ktx)
* `androidx.appcompat:appcompat`: [Notas de lanzamiento de AndroidX Appcompat](https://developer.android.com/jetpack/androidx/releases/appcompat)
* `com.google.android.material:material`: [Guía de inicio de Material Design Components para Android](https://material.io/develop/android/docs/getting-started)
* `androidx.constraintlayout:constraintlayout`: [Notas de lanzamiento de AndroidX ConstraintLayout](https://developer.android.com/jetpack/androidx/releases/constraintlayout)

#### CameraX

Un *toolkit* de Android Jetpack que simplifica el uso de la cámara del dispositivo, proporcionando una API consistente y fácil de usar para diversas funcionalidades de cámara.

* `androidx.camera:camera-core`
* `androidx.camera:camera-camera2`
* `androidx.camera:camera-lifecycle`
* `androidx.camera:camera-view`
* Puedes encontrar la documentación y ejemplos en la **[Guía general de CameraX](https://developer.android.com/media/camera/camerax)**.

#### USB Serial for Android

Una librería esencial para la comunicación de nuestra aplicación con el microcontrolador del vehículo a través de una conexión serial USB.

* `com.github.mik3y:usb-serial-for-android`: Puedes consultar el repositorio oficial en **[GitHub - usb-serial-for-android](https://github.com/mik3y/usb-serial-for-android)**.

#### OpenCV (Open Source Computer Vision Library)

Una potente librería para el procesamiento de imágenes y visión por computador, utilizada para tareas de análisis visual y toma de decisiones dentro de la aplicación.

* **Integración Local**: Es importante destacar que **OpenCV está integrado como un módulo local dentro de este proyecto de Android Studio**. Esto significa que los archivos binarios y la configuración necesaria de OpenCV ya están incluidos en este repositorio.
* `implementation(project(":OpenCV"))`: Esta línea en el `build.gradle` indica que el módulo `:OpenCV` es una parte intrínseca de este proyecto.
* Para documentación general sobre la librería, puedes visitar el sitio oficial de **[OpenCV](https://opencv.org/)**.

#### Librerías de Testing

Componentes estándar para realizar pruebas unitarias y de instrumentación en la aplicación.

* `junit:junit`: [Sitio oficial de JUnit 4](https://junit.org/junit4/faq.html)
* `androidx.test.ext:junit`: [Notas de lanzamiento de AndroidX Test Ext JUnit](https://developer.android.com/jetpack/androidx/releases/test)
* `androidx.test.espresso:espresso-core`: [Notas de lanzamiento de AndroidX Test Espresso](https://developer.android.com/jetpack/androidx/releases/espresso)

---

### Preparación del Proyecto Android

Para compilar y ejecutar esta aplicación en su entorno, siga estos pasos:

1.  **Requisitos Previos**:
    * Asegúrese de tener **Android Studio** instalado y configurado, incluyendo el SDK de Android necesario y las herramientas de Gradle.

2.  **Abrir el Proyecto**:
    * Abra este directorio directamente en Android Studio.

3.  **Sincronización de Gradle**:
    * Android Studio detectará automáticamente el proyecto y sus archivos `build.gradle`. Se le pedirá que sincronice el proyecto. Este paso es crucial, ya que Gradle descargará automáticamente todas las dependencias externas (AndroidX, CameraX, USB Serial, etc.) desde los repositorios de Maven configurados.
    * **No se requiere instalación de OpenCV**: Dado que OpenCV se incluye como un módulo local, no necesita realizar ninguna instalación o configuración adicional de OpenCV en su sistema; Gradle lo gestionará directamente desde el código fuente del proyecto. Simplemente asegúrese de que la estructura de carpetas incluya el módulo `:OpenCV` y que esté referenciado en el `settings.gradle`.

4.  **Compilar y Ejecutar**:
    * Una vez que la sincronización de Gradle finalice sin errores, podrá compilar el proyecto y ejecutar la aplicación en su dispositivo Android.

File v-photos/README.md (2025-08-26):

Vehicle's photos
====

This directory must contain 6 photos of the vehicle (from every side, from top and bottom)

---

### Vista Frontal
Carro - Vista Frontal

---

### Vista Trasera
Carro - Vista Trasera

---

### Lateral Izquierdo
Carro - Lateral Izquierdo

---

### Lateral Derecho
Carro - Lateral Derecho

---

### Vista Superior
Carro - Vista Superior

---

### Vista Inferior
Carro - Vista Inferior

---

¡Espero que les guste!

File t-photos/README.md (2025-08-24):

Team's photos
====

### Foto Oficial
Foto Oficial

---

### Foto Divertida
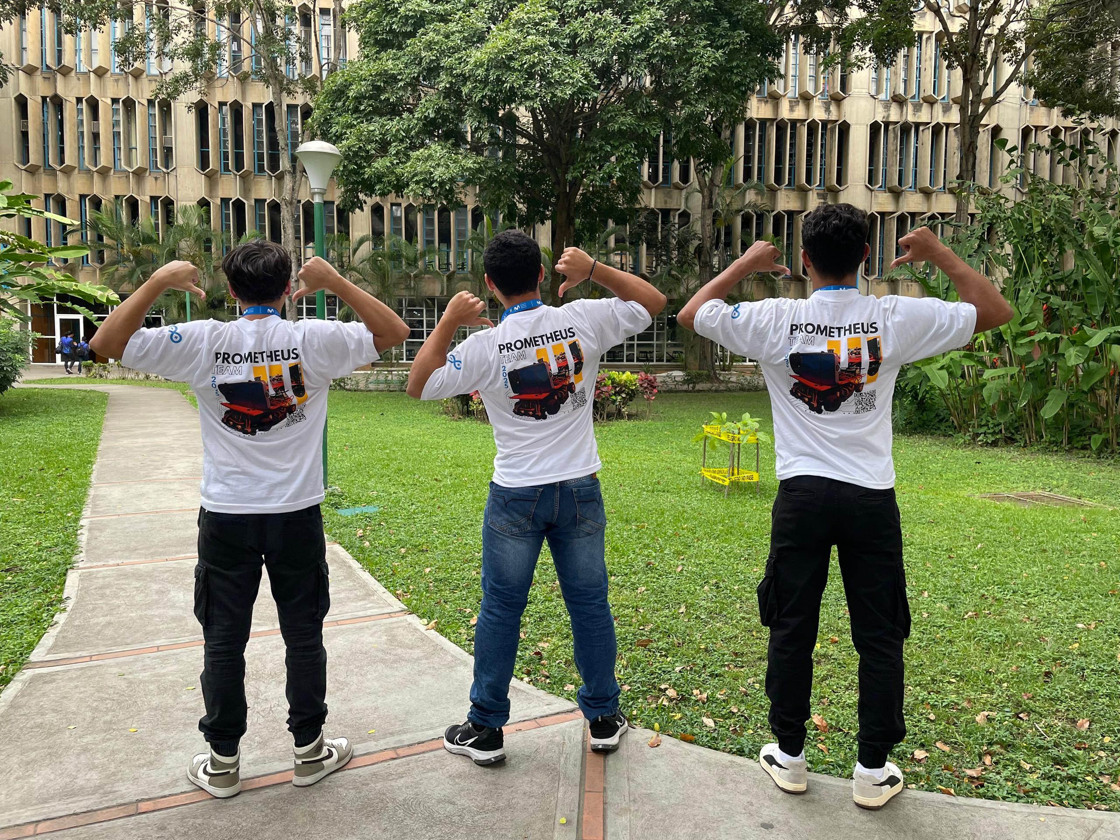
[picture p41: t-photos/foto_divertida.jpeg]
Foto Divertida


---

¡Espero que les guste!

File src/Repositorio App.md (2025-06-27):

# Enlace Repositorio APP Prometheus Team

### Aquí encontrarás el enlace a nuestro repositorio de GitHub con toda la programación de la aplicación WRO Prometheus.

[Ver Repositorio APP WRO Prometheus](https://github.com/SamFlips/APP-WRO-PROMETHEUS-TEAM/tree/master)

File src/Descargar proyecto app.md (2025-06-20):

# Enlace App Prometheus Team  

 ### Aqui encontraras un enlace a drive con el archivo .zip con todos los archivos de nuestra APP.

[Descargar Proyecto APP WRO Prometheus](https://drive.google.com/file/d/1VvdzdWbxGnchFslUwI8wQfkkwYPTyGRD/view?usp=drive_link)

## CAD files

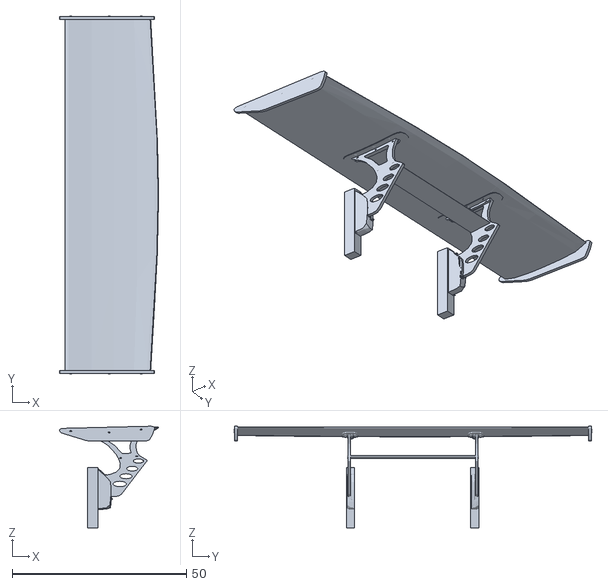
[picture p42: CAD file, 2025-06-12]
models/aleron_vehiculo.stl
28.5 x 102.7 x 29.2

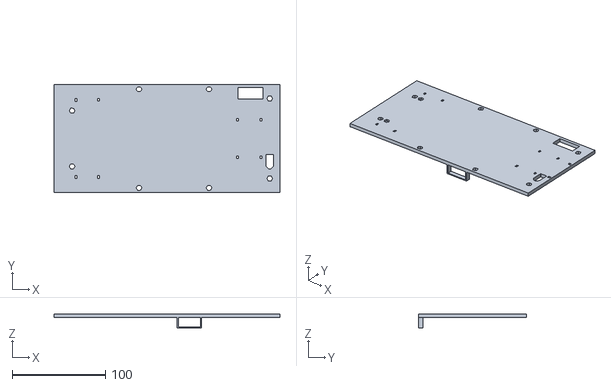
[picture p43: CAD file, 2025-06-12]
models/segundo_piso_vehiculo_ajustado.stl
242.0 x 116.0 x 15.0

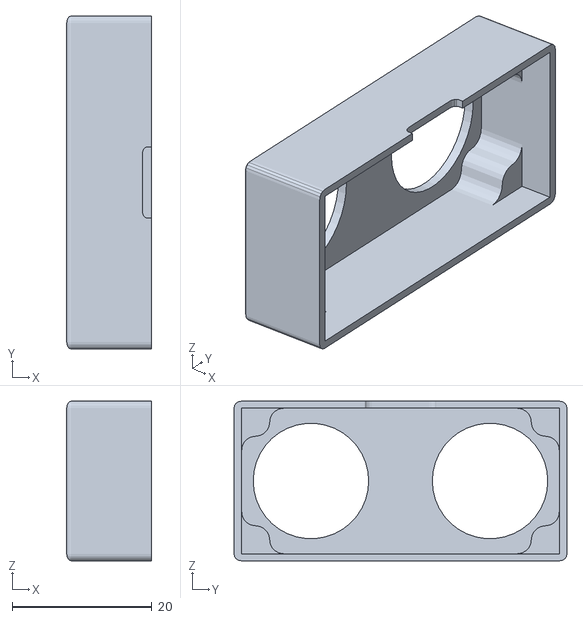
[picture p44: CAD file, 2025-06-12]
models/soporte_HC-SR04.stl
12.1 x 47.6 x 22.8

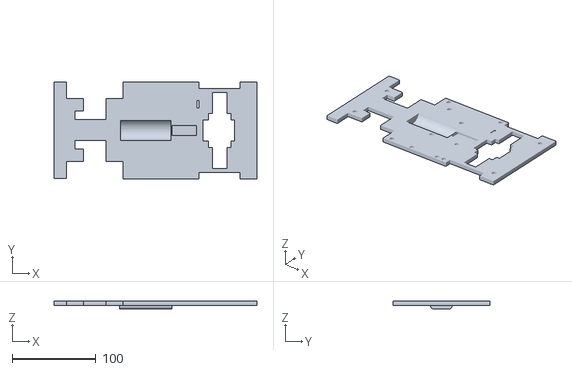
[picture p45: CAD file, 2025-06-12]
models/primer_piso_vehiculo_ajustado.stl
242.0 x 116.0 x 9.20

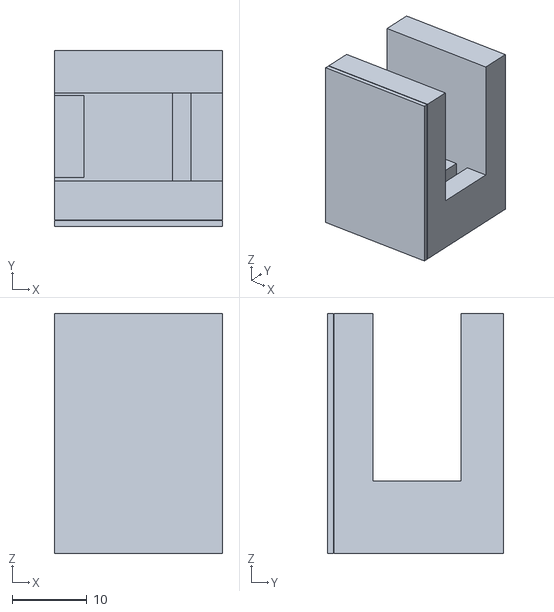
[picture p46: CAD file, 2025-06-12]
models/soporte_servo.stl
22.5 x 23.6 x 32.1

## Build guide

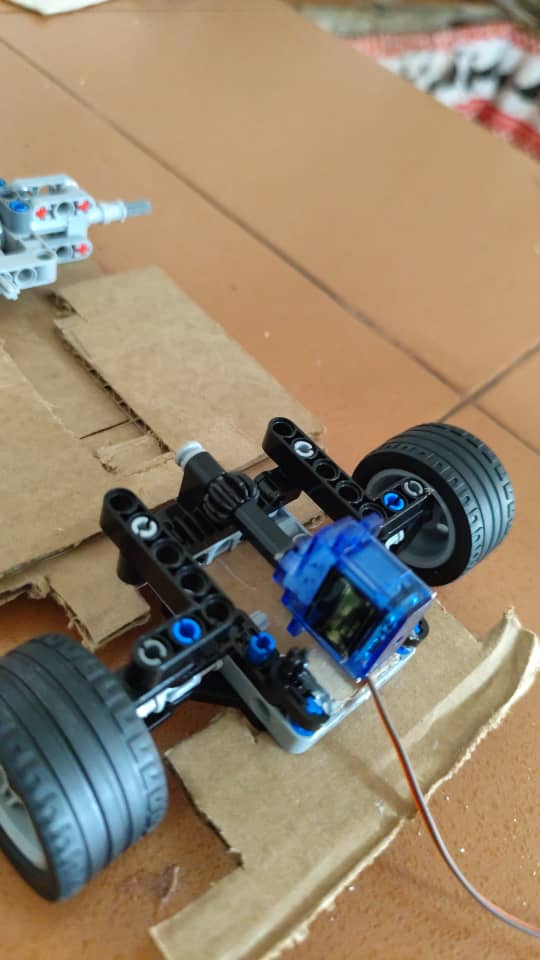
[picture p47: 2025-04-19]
other/montaje2.jpg

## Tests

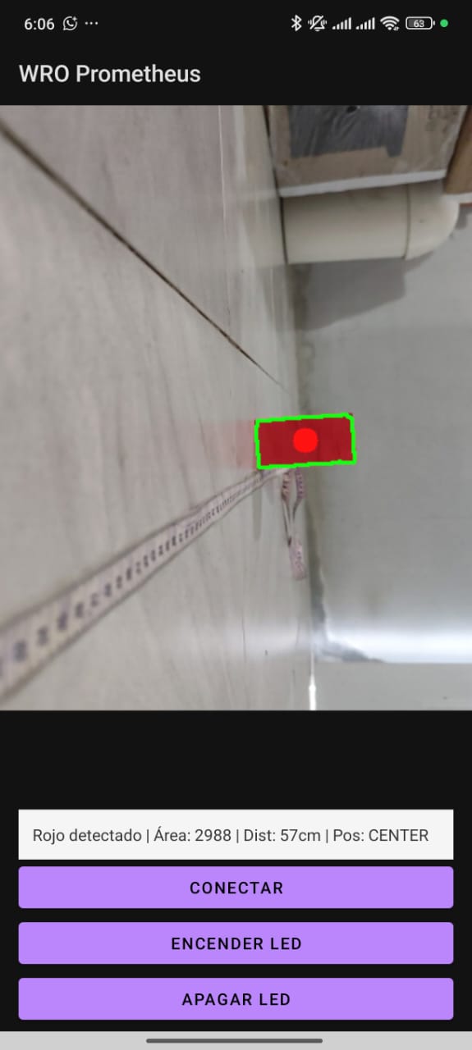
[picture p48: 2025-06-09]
other/pruebas.jpg

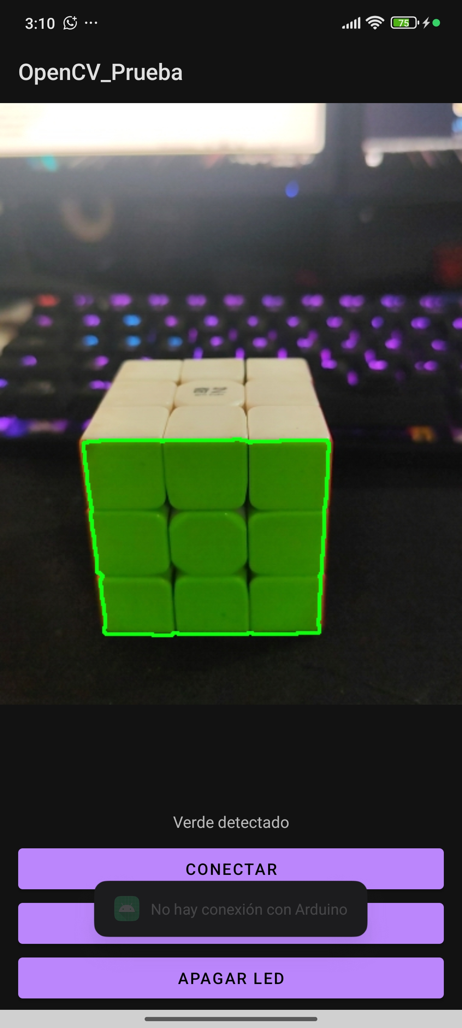
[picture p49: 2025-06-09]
other/app_prueba3.jpg

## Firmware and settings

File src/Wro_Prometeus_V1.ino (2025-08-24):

#include <Wire.h>
#include <Adafruit_TCS34725.h>
#include <MPU6050.h>
#include <ESP32Servo.h>
#include <ColorConverterLib.h>

Adafruit_TCS34725 tcs = Adafruit_TCS34725(TCS34725_INTEGRATIONTIME_2_4MS, TCS34725_GAIN_1X);
MPU6050 mpu;
Servo direccion;
#define I2C_SDA 21
#define I2C_SCL 22
const int MOTOR_RETROCESO_PIN = 19;  // Pin para motor de retroceso
const int MOTOR_PIN = 15;
const int SERVO_PIN = 13;
// Declaraciones de pines (usar pines analógicos como digitales)
#define LED_PIN 12      // Pin analógico A0 usado como digital para LED
#define BUZZER_PIN 14   // Pin analógico A1 usado como digital para buzzer


// Pin para sensor ultrasónico frontal (emergencia)
const int TRIG_FRONTAL = 4;
const int ECHO_FRONTAL = 36;

const int INTERRUPTOR_PIN = 27;  // Pin digital para el interruptor (usa pin con interrupt)

// Variables de estado del sistema
bool sistemaIniciado = false;
bool interruptorAnterior = false;
unsigned long tiempoDebounce = 0;
const unsigned long DEBOUNCE_DELAY = 50;

// ===== CONFIGURACIÓN DE SERVO =====
const int SERVO_RIGHT = 0;
const int SERVO_CENTER = 90;
const int SERVO_LEFT  = 180;

const int SERVO_OrientadoObjeto_LEFT = 130;
const int SERVO_OrientadoObjeto_RIGH = 50;

// Pines para sensores ultrasónicos
const int TRIG_DERECHO = 16;
const int ECHO_DERECHO = 39;
const int TRIG_IZQUIERDO = 17;
const int ECHO_IZQUIERDO = 34;

const int SERVO_CENTRADO = 90;

int contadorEntradaEstadoFinal = 0;

// Contador de líneas
int contadorLineas = 0;
int limiteLineas = 12;

int16_t ax, ay, az, gx, gy, gz;

float anguloZ = 0.0;        // Ángulo Yaw (giro alrededor del eje Z)
float pitch = 0.0;          // Ángulo Pitch (inclinación adelante/atrás)
float roll = 0.0;           // Ángulo Roll (inclinación lateral)
float anguloObjetivoGlobal = 0.0; // angulo recto para el giro

// Factores de peso para el filtro complementario
// K_ACC: Peso del acelerómetro (0.0 a 1.0). Un valor pequeño es común.
// K_GYRO: Peso del giroscopio (1.0 - K_ACC).
const float K_ACC = 0.02; // Puedes ajustar este valor. Más alto = más influencia del acelerómetro, más bajo = más influencia del giroscopio.
const float K_GYRO = 1.0 - K_ACC;

// Ángulos de giro modificables para cada sentido
float giroObjetivoAzul = 90.0;    // Giro a la izquierda para línea azul
float giroObjetivoNaranja = 90.0; // Giro a la derecha para línea naranja (modificable)


float toleranciaGiro = 5.0;
float offsetGz = 0.0;
float offsetGx = 0.0; // Offset del giroscopio en X (Roll)
float offsetGy = 0.0; // Offset del giroscopio en Y (Pitch)

float umbralGiro = 0.5;//1.0 antes
float umbralReposo = 0.5;

//mantener este timeout o aumentarlo para que termine el giro correctamente.
unsigned long lastTime, startTime, timeoutGiro = 1500;

unsigned long lastYawPrint = 0; // Para el intervalo de impresión del Yaw
const long YAW_INTERVAL = 300; // Intervalo de impresión en ms

// Variables para control de centrado
bool enGiro = false;
unsigned long tiempoFinGiro = 0;
const unsigned long tiempoEsperaPosgiro = 0;
const int anguloCorreccionMax = 50;// normal 50 16/07/2025
const unsigned long intervaloCentrado = 100;
unsigned long ultimoTiempoCentrado = 0;


// SISTEMA HÍBRIDO MPU6050 + QMC5883L

// Dirección I2C del QMC5883L
#define QMC5883L_ADDRESS 0x0D

// Registros del QMC5883L
#define QMC5883L_DATA_OUTPUT_X_LSB 0x00
#define QMC5883L_DATA_OUTPUT_X_MSB 0x01
#define QMC5883L_DATA_OUTPUT_Y_LSB 0x02
#define QMC5883L_DATA_OUTPUT_Y_MSB 0x03
#define QMC5883L_DATA_OUTPUT_Z_LSB 0x04
#define QMC5883L_DATA_OUTPUT_Z_MSB 0x05
#define QMC5883L_STATUS 0x06
#define QMC5883L_CONTROL_1 0x09
#define QMC5883L_CONTROL_2 0x0A
#define QMC5883L_SET_RESET_PERIOD 0x0B

// Variables globales necesarias 
float declinacionMagnetica = -9.0; // Para Venezuela - ajustar según tu ubicación
float offsetAngular = 0.0; // Offset adicional si necesitas ajustar el norte de referencia
/*
// Valores de calibración
float xOffset = -242.5;    // Tu valor obtenido
float yOffset = 92.5;      // Tu valor obtenido  
float xScale = 1.008;      // Tu valor obtenido
float yScale = 0.992;      // Tu valor obtenido
*/
float xOffset = -427.5;//0.0;    
float yOffset = -199.0;//0.0;    
float xScale = 1.021;//1.0;     
float yScale = 0.980;//1.0;
// ========== VARIABLES GLOBALES ADICIONALES ==========
float anguloMagnetometro = 0;
float factorCorreccion = 0.0;
unsigned long ultimaCorreccionMag = 0;
const unsigned long INTERVALO_MAGNETOMETRO = 500; // ms
const float UMBRAL_DIFERENCIA_MAXIMA = 5.0; // grados
const float FACTOR_FUSION_COMPLEMENTARIO = 0.98; // 0.98 = 98% gyro, 2% mag

// Buffer para promedio móvil del magnetómetro
const int BUFFER_SIZE_MAGNETOMETRO = 5;
float bufferMagnetometro[BUFFER_SIZE_MAGNETOMETRO];
int indiceBufer = 0;
bool bufferLleno = false;


// Variables para pausar centrado durante detección
bool pausarCentrado = false;
unsigned long tiempoInicioDeteccion = 0;
const unsigned long tiempoPausaCentrado = 100;

// Variables para detección de líneas
bool lineaNaranjaDetectada = false;
unsigned long tiempoUltimaDeteccion = 0;
const unsigned long tiempoEsperaDeteccion = 500;
// Variables para direccionalidad
enum SentidoGiro {
  INDEFINIDO,
  IZQUIERDA,  // Detectó azul primero
  DERECHA     // Detectó naranja primero
};

SentidoGiro sentidoVehiculo = INDEFINIDO;
bool primeraDeteccion = true;

// ==================== VARIABLES PID PARA GIROS ====================

// Variables para controlador PID de giros
struct PIDController {
  float kp;           // Ganancia proporcional
  float ki;           // Ganancia integral
  float kd;           // Ganancia derivativa
  float error_anterior;
  float integral;
  float integral_max; // Límite para evitar windup
  unsigned long tiempo_anterior;
};

// Configuración del PID para giros
PIDController pidGiro = {
  .kp = 2.5,          // Ganancia proporcional - ajusta respuesta principal
  .ki = 0.8,          // Ganancia integral - elimina error en estado estacionario
  .kd = 0.4,          // Ganancia derivativa - reduce oscilaciones
  .error_anterior = 0,
  .integral = 0,
  .integral_max = 30, // Límite para integral windup
  .tiempo_anterior = 0
};

// Variables adicionales para control PID
float anguloObjetivoActual = 0;
bool giroEnProceso = false;
const float TOLERANCIA_PID = 2.0;      // Tolerancia más estricta con PID

// ==================== VARIABLES PID PARA CENTRADO ====================

// Variables para controlador PID de centrado
struct PIDCentrado {
  float kp;           // Ganancia proporcional
  float ki;           // Ganancia integral  
  float kd;           // Ganancia derivativa
  float error_anterior;
  float integral;
  float integral_max; // Límite para evitar windup
  unsigned long tiempo_anterior;
  bool inicializado;  // Para manejar primera ejecución
};

// Configuración del PID para centrado
PIDCentrado pidCentrado = {
  .kp = 3.8,          // Ganancia proporcional - respuesta principal al error
  .ki = 0.7,          // Ganancia integral - elimina error residual
  .kd = 0.8,          // Ganancia derivativa - reduce oscilaciones
  .error_anterior = 0,
  .integral = 0,
  .integral_max = 20, // Límite para integral windup
  .tiempo_anterior = 0,
  .inicializado = false
};

// Variables adicionales para control PID del centrado
const float TOLERANCIA_CENTRADO_PID = 5.0;    // Tolerancia más estricta
const float ERROR_MAXIMO_CENTRADO = 30.0;     // Error máximo esperado
const float FACTOR_SUAVIZADO = 0.7;           // Para suavizar cambios bruscos

// Buffer para comandos serie
String comandoRecibido = "";
  bool comandoListo = false;


//-------variables de evasion de objetos--------------

// Estados del sistema integrado
enum EstadoSistema {
  ESTADO_NORMAL,      // Navegación normal + detección de líneas + recepción comandos
  SIGUIENDO_OBJETO,   // Siguiendo objeto detectado por app
  ESQUIVANDO,         // Esquivando objeto
  ESTADO_DETENCION_FINAL
};
float distanciaFrontalInicial = 0.0;
const float TOLERANCIA_DISTANCIA_FINAL = 2.0;  // cm de tolerancia aceptable

// Variables para recepción serial optimizada (del código de esquive)
const int BUFFER_SIZE = 32;
char buffer[BUFFER_SIZE];
int bufferIndex = 0;

// Variables para parsing ultra rápido
char colorDetectado = 'N';
int distanciaObjeto = 0;
char orientacionObjeto = 'C';

// Variables de estado
EstadoSistema estadoActual = ESTADO_NORMAL;
char colorObjetivo = 'N';
unsigned long tiempoEsquive = 0;
int etapaEsquive = 0;
char lastOrientation = 'X';

// Configuración de distancias para esquive
const int DISTANCIA_ROJO = 40;//35;    // Distancia de esquive para objetos rojos
const int DISTANCIA_VERDE = 45;//40;   // Distancia de esquive para objetos verdes
const int DISTANCIA_EMERGENCIA = 8;
// Tiempos de esquive por color (en milisegundos)
const unsigned long TIEMPO_ESQUIVE_VERDE = 800;   // Tiempo para esquivar verde
const unsigned long TIEMPO_ESQUIVE_ROJO = 800;   // Tiempo para esquivar rojo
const unsigned long TIEMPO_RETORNO_VERDE = 600;   // Tiempo de retorno para verde
const unsigned long TIEMPO_RETORNO_ROJO = 600;    // Tiempo de retorno para rojo

// Variables para almacenar los tiempos actuales
unsigned long tiempoEsquiveActual = 0;
unsigned long tiempoRetornoActual = 0;

// Variables para recordar último color detectado
char ultimoColorDetectado = 'N';           // Último color válido recibido
unsigned long tiempoUltimoColor = 0;       // Timestamp del último color detectado
const unsigned long TIEMPO_MEMORIA_COLOR = 0; // 4 segundos de memoria

// Variables para función de emergencia
bool emergenciaActivada = false;
unsigned long tiempoUltimaEmergencia = 0;
const unsigned long TIEMPO_ESPERA_EMERGENCIA = 2000; // Evitar activaciones múltiples
char colorEmergencia = 'N';

// Variables para interrupción de cruce
volatile bool interrupcionCruce = false;
volatile char comandoInterrupcion = 'N';
bool cruceEnProceso = false;
//------------------- Fin de variables de esquive--------------

// ==================== CONFIGURACIÓN Y VARIABLES SHARP ====================

// Pines para sensores Sharp diagonales
const int SHARP_DIAGONAL_IZQ_PIN = 32;  // Pin analógico para sensor Sharp izquierdo
const int SHARP_DIAGONAL_DER_PIN = 33;  // Pin analógico para sensor Sharp derecho

// Variables para esquive diagonal por sensores Sharp
bool esquiveDiagonalActivo = false;
unsigned long tiempoInicioEsquiveDiagonal = 0;
unsigned long tiempoUltimaDeteccionSharp = 0;
char direccionEsquiveDiagonal = 'N'; // 'I' = izquierda, 'D' = derecha
int etapaEsquiveDiagonal = 0;

// Configuración para sensores Sharp diagonales
const float DISTANCIA_SHARP_EMERGENCIA = 15.0;     // 10cm de detección
const unsigned long TIEMPO_CRUCE_DIAGONAL = 500;  // Tiempo de cruce diagonal
const unsigned long TIEMPO_ESPERA_SHARP = 100;     // Evitar detecciones múltiples

// Sistema de prioridades para gestión de emergencias
enum PrioridadEmergencia {
  PRIORIDAD_NORMAL,
  PRIORIDAD_RETROCESO,  // Máxima prioridad
  PRIORIDAD_ESQUIVE     // Prioridad normal
};
PrioridadEmergencia prioridadActual = PRIORIDAD_NORMAL;

// Variables mejoradas para retroceso de emergencia
const int DISTANCIA_RETROCESO_EMERGENCIA = 13;    // Distancia mínima para activar retroceso (cm)
const unsigned long TIEMPO_RETROCESO = 1500;     // Tiempo de retroceso en ms
const unsigned long TIMEOUT_RETROCESO = 3000;    // Timeout de seguridad para retroceso
bool retrocesoPorEmergencia = false;    
// Variables de control temporal
unsigned long tiempoInicioRetroceso = 0;          
unsigned long tiempoUltimaVerificacionRetroceso = 0; 
const unsigned long INTERVALO_VERIFICACION_RETROCESO = 50; // Verificación cada 100ms
const unsigned long TIEMPO_ESPERA_POST_RETROCESO = 100;     // Tiempo de espera después del retroceso
bool motorRetrocesoConfigurado = false;  // controlar configuración de motores

bool retrocesoOrientadoActivo = false;
unsigned long tiempoInicioRetrocesoOrientado = 0;
const unsigned long TIEMPO_RETROCESO_ORIENTADO = 700; // 1 segundo (modificable)
int direccionRetroceso = SERVO_CENTRADO;

// Variables para control de retroceso post-giro
unsigned long tiempoInicioEvaluacion = 0;

// ============== CONSTANTES DE ÁNGULOS ==============
const float GIRO_MAXIMO = 75.0;      // Giro máximo - obstáculo muy cerca
const float GIRO_ALTO = 70.0;        // Giro alto - obstáculo cerca
const float GIRO_MEDIO_ALTO = 67.0;  // Giro medio-alto
const float GIRO_MEDIO = 63.0;       // Giro medio
const float GIRO_MEDIO_BAJO = 58.0;  // Giro medio-bajo
const float GIRO_BAJO = 53.0;        // Giro bajo - obstáculo lejano
const float GIRO_MINIMO = 48.0;      // Giro mínimo - obstáculo muy lejano

// Constantes de tiempos de retroceso (en milisegundos)
const unsigned long TIEMPO_RETROCESO_MAXIMO = 0;     // Para GIRO_MAXIMO (70°)
const unsigned long TIEMPO_RETROCESO_ALTO = 0;       // Para GIRO_ALTO (55°)
const unsigned long TIEMPO_RETROCESO_MEDIO_ALTO = 0;  // Para GIRO_MEDIO_ALTO (45°)
const unsigned long TIEMPO_RETROCESO_MEDIO = 0;       // Para GIRO_MEDIO (35°)
const unsigned long TIEMPO_RETROCESO_MEDIO_BAJO = 0;  // Para GIRO_MEDIO_BAJO (30°)
const unsigned long TIEMPO_RETROCESO_BAJO = 0;        // Para GIRO_BAJO (25°)
const unsigned long TIEMPO_RETROCESO_MINIMO = 0;      // Para GIRO_MINIMO (20°)
const unsigned long TIEMPO_RETROCESO_DEFECTO = 0;     // Valor por defecto
const unsigned long TIMEOUT_RETROCESO_MAXIMO =1300;  // Timeout de seguridad (2.5 segundos)

unsigned long tiempoRetrocesoActual = 0;  // Variable para tiempo dinámico de retroceso
//
bool sistemaActivo = false;  // Estado del sistema (activo/inactivo)

// Variable para controlar giro antes de estacionamiento
bool giroParaEstacionamiento = false;

// tiempo de finalizacion del codigo para avance final
unsigned long tiempoInicio = millis();
//unsigned long duracionCiclo = 3000; // 5 segundos en milisegundos

 // Añadir esta línea con las otras variables de estado/tiempo
unsigned long tiempoInicioDetencionFinal = 0;

// Variables globales para el control de arranque del motor
unsigned long tiempoInicioSistema = 0;
bool motorArrancado = false;
const unsigned long DELAY_ARRANQUE_MOTOR = 1000; // 1 segundo en milisegundos

// Función auxiliar para generar pulsos cortos (volumen bajo)
void buzzerVolumenBajo(int duracionTotal) {
  int tiempoTranscurrido = 0;
  while (tiempoTranscurrido < duracionTotal) {
    // Toca un tono corto de 2000 Hz por 20ms
    tone(BUZZER_PIN, 1500, 100);
    delay(100); // Pausa de 80ms + 20ms del tono
    tiempoTranscurrido += 100;
  }
}

void esperarInterruptor() {
  ////ln(F("Esperando activacion del interruptor (LOW)..."));
  
  // LED parpadea lentamente mientras espera
  bool ledState = false;
  unsigned long ultimoParpadeo = 0;

  
  while (digitalRead(INTERRUPTOR_PIN) == HIGH) {  // Espera a que pase a LOW
    unsigned long ahora = millis();
    
    // Parpadeo lento del LED (cada 500ms)
    if (ahora - ultimoParpadeo > 500) {
      ledState = !ledState;
      digitalWrite(LED_PIN, ledState);
      ultimoParpadeo = ahora;
    }
    
    delay(10);
  }
  
  // Cuando el interruptor pasa a LOW, activar sistema
  digitalWrite(LED_PIN, LOW); // Apagar LED de espera
  delay(50); // Pequeña pausa para debounce
  iniciarSistema();
} 
  // Función mejorada para verificar el interruptor y controlar el sistema
void verificarInterruptor() {
  bool estadoActual = digitalRead(INTERRUPTOR_PIN);
  unsigned long tiempoActual = millis();
  
  // Debounce del interruptor
  if (estadoActual != interruptorAnterior) {
    tiempoDebounce = tiempoActual;
  }
  
  if ((tiempoActual - tiempoDebounce) > DEBOUNCE_DELAY) {
    if (estadoActual != interruptorAnterior) {
      // Cambio de estado confirmado
      if (estadoActual == LOW) {
        // Interruptor en LOW - INICIAR SISTEMA
        if (!sistemaActivo) {
          iniciarSistema();
        }
      } else {
        // Interruptor en HIGH - DETENER SISTEMA
        if (sistemaActivo) {
          detenerSistema();
        }
      }
      interruptorAnterior = estadoActual;
    }
  }
}
// LED indicador de sistema activo - 3 parpadeos rápidos con sonido
void indicadorSistemaActivo() {
  for (int i = 0; i < 3; i++) {
    digitalWrite(LED_PIN, HIGH);
    //buzzerVolumenBajo(500);  // 100ms con pulsos cortos
    digitalWrite(LED_PIN, LOW);
    delay(100);
  }
}
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
void loop() {
  // PRIMERA PRIORIDAD: Verificar interruptor SIEMPRE
  verificarInterruptor();
  
  verificarArranqueMotor();

  // Si el sistema no está activo, no ejecutar nada más
  if (!sistemaActivo) {
    delay(50);  // Pequeña pausa para no saturar el procesador
    return;
  }
   if (contadorLineas>= limiteLineas){
    estadoActual ==  ESTADO_DETENCION_FINAL;
  }
    // EJECUTAR SIEMPRE (independiente de comandos seriales)
  actualizarGiro();
   detectarColor();
 /*if (estadoActual != ESTADO_DETENCION_FINAL){
    detectarColor();
  }*/
   // MÁQUINA DE ESTADOS - Solo ejecutar si no hay procesos de alta prioridad
  switch(estadoActual) {
    case ESTADO_NORMAL:
      //centrara vehiculo despues del primer giro
       if (!enGiro && 
          prioridadActual == PRIORIDAD_NORMAL && 
          !esquiveDiagonalActivo && 
          !retrocesoPorEmergencia && !primeraDeteccion) {
        centrarVehiculo();
        //Serial.println("normal");
          }
      break;
      
    case SIGUIENDO_OBJETO:
      if (prioridadActual == PRIORIDAD_NORMAL && 
          !esquiveDiagonalActivo && 
          !retrocesoPorEmergencia) {
          //  Serial.println("siguiendo");
        orientarServoSeguimiento();
        
      }
      break;
      
    case ESQUIVANDO:
      if (prioridadActual == PRIORIDAD_NORMAL && 
          !esquiveDiagonalActivo && 
          !retrocesoPorEmergencia) {
         //   Serial.println("esquive");
        procesarEsquive();
      }
      break;
   
    case ESTADO_DETENCION_FINAL:
     if (contadorEntradaEstadoFinal >= 1){
       // Primer pitido (tono agudo por 50 ms)
      //  tone(BUZZER_PIN, 2500, 50);
        delay(100); // Espera 50ms del tono + 50ms de pausa

        // Segundo pitido
     //   tone(BUZZER_PIN, 2500, 50);

        contadorEntradaEstadoFinal += 1; 
      }
      // Avanzar en línea recta durante 2.5 segundos
      if (millis() - tiempoInicioDetencionFinal < 2000) {
        if (!enGiro && 
          prioridadActual == PRIORIDAD_NORMAL) {
        centrarVehiculo();

        //Serial.println("normal");
          }
        
        // Debug cada segundo
       /* static unsigned long ultimoDebug = 0;
        if (millis() - ultimoDebug > 1000) {
          //("Avance final - Tiempo restante: ");
          //(2500 - (millis() - tiempoInicioAvanceFinal));
          //ln(" ms");
          ultimoDebug = millis();
        }*/
        
      } else {
        //ln("Avance final completado - Motor detenido");
        detenerRobot();
       // estadoActual = ESTADO_NORMAL; // Opcional: volver a estado normal
        
      }
      break;
  }  
  // ===== RESTO DE TU CÓDIGO SOLO SE EJECUTA SI EL SISTEMA ESTÁ ACTIVO =====
  
  // MÁXIMA PRIORIDAD: Retroceso de emergencia (SOLO si NO está girando)
  if (prioridadActual == PRIORIDAD_RETROCESO && !giroEnProceso && !retrocesoOrientadoActivo && estadoActual !=ESTADO_DETENCION_FINAL){
    if (retrocesoPorEmergencia) {
      procesarRetrocesoEmergencia();
    }
    return;
  }

  // Verificar y activar retroceso de emergencia (SOLO si NO está girando)
  if (!giroEnProceso && verificarRetrocesoEmergencia() && !retrocesoOrientadoActivo && estadoActual != ESTADO_DETENCION_FINAL) {
    procesarRetrocesoEmergencia();
    return;
  }
  
  // ALTA PRIORIDAD: Retroceso post-giro
  if (procesarRetrocesoPostGiro()  && estadoActual != ESTADO_DETENCION_FINAL) {
    // El retroceso está activo, no ejecutar nada más
    return;
  }
  
  

  // PRIORIDAD ALTA: Procesar comandos seriales
  /*if (Serial.available() > 0) {
    processSerialData();
    if (contadorLineas>= limiteLineas){
    estadoActual ==  ESTADO_DETENCION_FINAL;
    } else if (estadoActual == SIGUIENDO_OBJETO && !emergenciaActivada) {
      if (verificarEmergencia()) {
        estadoActual = ESQUIVANDO;
        etapaEsquive = 0;
        tiempoEsquive = millis();
        colorObjetivo = colorEmergencia;
      }
    }

    if (emergenciaActivada && estadoActual == ESQUIVANDO) {
      emergenciaActivada = false;
    }
  }
  */
 
   if (!primeraDeteccion) {
    
     // Verificar obstáculos diagonales SOLO si NO está girando
      if (!esquiveDiagonalActivo && !giroEnProceso && verificarObstaculoDiagonal()) {
         // Se activó esquive diagonal
       }
       // Procesar esquive diagonal si está activo Y NO está girando
      if (esquiveDiagonalActivo && !giroEnProceso) {
            procesarEsquiveDiagonal();
       }
  
   }

  // Mostrar el valor cada 300 ms
  if (millis() - lastYawPrint >= YAW_INTERVAL) {
        Serial.print("Yaw: ");
        //Serial.print(yawFiltrado);
        Serial.print(anguloZ);
        Serial.print("°  ");
        lastYawPrint = millis();
        
    }
 
  delay(20);
}

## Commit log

2025-04-19 Rename power supply diagram.jpeg to power_supply_diagram.jpeg
2025-06-12 diagramas de los codigo
